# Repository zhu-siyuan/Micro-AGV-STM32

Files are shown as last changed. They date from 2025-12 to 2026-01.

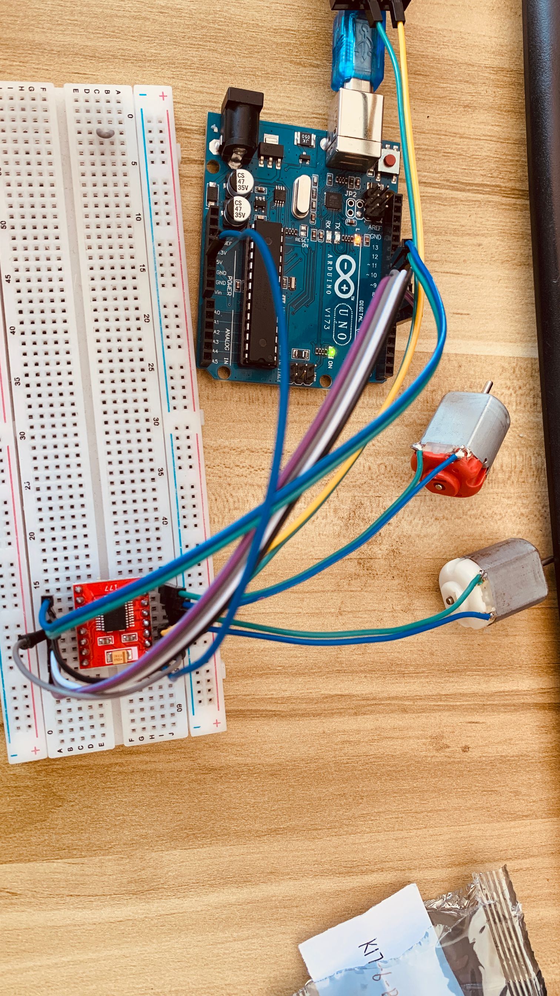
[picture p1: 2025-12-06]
Docs/Datasheets/电机驱动详情/实物接线.png

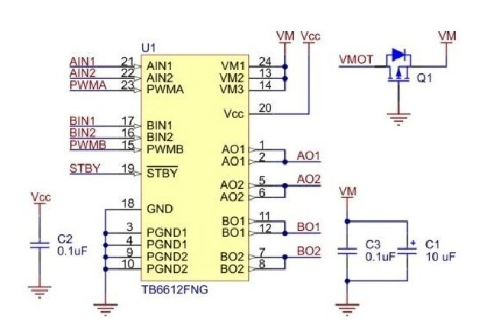
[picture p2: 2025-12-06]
Docs/Datasheets/电机驱动详情/原理图.png

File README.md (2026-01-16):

# 🏎️ Micro-AGV-STM32 (工业级桌面移动机器人)

> **"不仅仅是玩具，而是遵循工业设计标准开发的 Micro-AGV 移动平台。"**

## 📖 项目简介 (Introduction)

本项目旨在研发一款**具备工业级研发标准的桌面级三轮全向移动小车 (Micro-AGV)**。
区别于市面上常见的“飞线+胶带”式玩具车，本项目严格遵循 **SOP (标准作业程序)**，采用 **V模型开发流程**，旨在验证从需求分析、GitHub 版本管理、PCB 集成设计到结构堆叠的全套正规军研发流程。

### 核心特性 (Key Features)
*   **🤖 闭环控制 (PID)**：摒弃开环控制，引入霍尔编码器反馈，实现速度与航向的精准修正。
*   **📡 工业级通信协议**：自定义定长数据帧（帧头+校验+帧尾），具备通信容错与失效保护机制。
*   **🏗️ 模块化软件架构**：基于 HAL 库，严格分层 (Drivers / Middlewares / Application)，解耦硬件细节。
*   **🛡️ 全包裹工业设计**：3D 打印外壳，隐藏式走线与电池仓设计，提升整机一体性。

---

## 🛠️ 系统架构 (System Architecture)

### 1. 硬件选型 (Hardware)
| 模块 | 型号/规格 | 选型理由 |
| :--- | :--- | :--- |
| **主控 MCU** | STM32F103C8T6 | 生态成熟，IO 资源满足 PWM/UART/编码器需求 |
| **电机驱动** | TB6612FNG | 双路 H 桥，高效率，低发热，体积小 |
| **动力系统** | JGA25-370| **带霍尔编码器**，支持 AB 相测速 (PID 基础) |
| **电源系统** | 2×18650 (7.4V) | 配合 LM2596 稳压模块，抗干扰能力强 |
| **通信模块** | HC-05 蓝牙 | 串口透传，兼容性好 |

### 2. 软件架构 (Software)
本项目采用分层架构设计：
- **📂 Application (业务层)**: 状态机管理 (待机/遥控/急停)、指令解析。
- **📂 Middlewares (功能层)**: PID 算法库、运动学解算 (Kinematics)、电机控制逻辑。
- **📂 Drivers (驱动层)**: 基于 STM32 HAL 库封装 GPIO, PWM, UART, EXTI。

---

## 📡 通信协议 (Communication Protocol)

为保证通信可靠性，拒绝单字符控制。采用 **定长数据帧** 格式：
**波特率：** 9600

| 字节索引 | 定义 | 值/说明 |
| :--- | :--- | :--- |
| **0** | **帧头 (Header)** | `0xA5` (固定，用于数据对齐) |
| **1** | **功能字 (Func)** | `0x01`: 遥控模式 <br> `0x02`: PID参数整定 |
| **2** | **数据 X** | X轴速度 (int8, -127~127) |
| **3** | **数据 Y** | Y轴速度 (int8, 预留给全向轮) |
| **4** | **数据 Omega** | 转向速度 (int8, -127~127) |
| **5** | **校验位 (Check)** | Sum Check (前5字节之和的低8位) |
| **6** | **帧尾 (Tail)** | `0x5A` (固定) |

> **失效保护 (Fail-Safe)**: 若连续 500ms 未收到合法数据帧，小车将自动急停。

---

## 📂 目录结构 (Directory Structure)
```text
Micro-AGV-STM32/
├── Docs/               # 项目文档 (可行性报告, Datasheets)
├── Hardware/           # 硬件工程 (Altium Designer/嘉立创 EDA)
│   ├── Schematic/      # 原理图
│   └── PCB/            # PCB源文件 & Gerber
├── Mechanical/         # 结构工程 (SolidWorks)
│   └── Export/         # STL/DXF 加工文件
├── Firmware/           # 嵌入式代码 (Keil/VSCode)
│   ├── Core/           # CubeMX 生成代码
│   ├── Drivers/        # 硬件驱动
│   └── App/            # 核心业务逻辑
└── README.md           # 项目说明书
```
---

## 👥 核心团队 (Team)

| 成员 | 角色 | 职责 |
| :--- | :--- | :--- |
| **@zhu-siyuan** | **PM & Software** | 项目管理、架构设计、STM32 固件开发、PID 调试 |
| **@min-huang-HW** | **Hardware** | 硬件选型、原理图/PCB 设计、电路焊接与测试 |
| **@yuying-qin-MD** | **Mechanical** | 工业设计、3D 建模 (SolidWorks)、结构总装 |

---

> Powered by **Micro-AGV Research Team**. 
> *Documentation is code.*

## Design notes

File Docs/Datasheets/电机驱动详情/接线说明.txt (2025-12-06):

uno的控制引脚接线可以看一下代码程序

*这个模块驱动电机需要STBY和VM同时给3.3V或者5V的高电平

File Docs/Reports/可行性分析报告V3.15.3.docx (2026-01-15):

桌面级三轮全向移动小车

可行性分析报告

编写： | 朱思源，覃钰莹，黄敏
审核：
版本号： | 3.15.3
修改时间： | 2026年1月5日

目 录

# 1、 引言

## (1) 编写目的

为编写产品开发可行性分析报告，旨在系统性评估项目的技术实现路径、资源匹配度及风险边界。该报告通过跨部门协同论证，确保核心设计方案在成本、周期与性能三者间取得最优平衡，为决策层提供量化依据，避免因关键要素预判缺失导致的重大方向偏离或资源浪费。

### 1. 项目背景

目前市面上常见的入门级蓝牙小车（如淘宝通用套件）普遍存在以下痛点：

(1) 工程化程度低：硬件集成粗糙，常采用裸露的“飞线”连接方式，线束杂乱且缺乏基本的捆扎与应力释放设计。这导致在运动或振动中连接器易松动、线材易疲劳断裂，供电与信号稳定性差，整体结构脆弱，故障率高。
(2) 软件架构缺失：配套代码多为单一文件的顺序“面条式”堆砌，硬件驱动、控制逻辑与用户交互高度耦合。缺乏清晰的分层（如驱动层、算法层、应用层）与模块化设计，导致代码可读性差、功能复用困难，任何修改都可能引发意外问题，严重阻碍二次开发与教学深化。
(3) 用户体验粗糙：往往仅提供最基础的遥控功能，缺乏运行状态提示（如电量、实时速度、连接状态）等直观反馈。外观多为开放式裸板或简易亚克力叠层，缺乏一体化封装与人性化设计，使得产品显得廉价、不稳固，且操作互动感薄弱。
(4) 基于公司对新人的培养要求，本项目组计划以“三轮差速底盘”为核心载体，不追求车体体积的盲目扩大，而是追求单位体积内的技术密度与工艺完成度。我们将挑战在有限的尺寸内，实现稳定的直线循迹、丝滑的蓝牙操控以及极具科技感的外观封装。

### 2. 术语定义

为了确保项目组内部沟通的一致性，特定义以下核心术语：

(1) Micro-AGV：微型自动导引车[1]。本项目中指代我们研发的蓝牙小车，强调其不仅是玩具，而是遵循工业设计标准开发的移动平台。
(2) 三轮差速模型(Differential Drive)：通过控制左右两个驱动轮的速度差来实现转向，配合后置/前置万向轮支撑的运动结构。
(3) SOP(Standard Operating Procedure)：标准作业程序。本项目中特指包括Git代码提交规范、PCB设计规范、结构公差分析在内的一系列研发铁律。
(4) MVP(Minimum Viable Product)：最小可行性产品。指优先交付核心功能（如蓝牙遥控跑通），再迭代高级功能（如外观件、PID调优）的开发策略。
(5) 开环控制（Open-Loop Control）：开环控制是指控制系统不依赖输出结果的反馈信息，仅根据预设的输入指令或控制规律直接驱动执行机构，对被控对象进行控制。
(6) 闭环控制（Closed-Loop Control）：闭环控制（又称反馈控制）是指控制系统通过传感器检测被控对象的实际输出，并将其与目标值（设定值）比较，根据偏差调整控制指令，直至输出接近或达到目标值。
(7) PWM(Pulse Width Modulation)：脉冲宽度调制。本项目中用于通过调节占空比来精确控制电机的转速，是调速的核心手段。
(8) UART透传(Serial Transparent Transmission)：蓝牙通信模式。指手机端与车载蓝牙模块之间建立一条“隐形的串口线”，数据不经处理直接转发给MCU，确保通信协议的自定义灵活性。
(9) 固件(Firmware)：运行在STM32微控制器内部的底层驱动程序与控制逻辑，区别于运行在手机端的APP软件。
(10) PID（Proportional-Integral-Derivative）：PID控制器是一种在工业控制、机器人、自动化系统中广泛使用的反馈控制算法，通过“比例（P）”、“积分（I）”、“微分（D）”三个环节的组合，根据系统输出与目标值的偏差自动调整控制量，使系统输出快速、稳定地逼近目标值。
(11) 阶跃响应（Step Response）：系统在输入为阶跃信号时所产生的输出随时间变化的过程。

# 2、 现有产品分析

## (1) 企业现有产品分析

企业现有一款四轮蓝牙小车，如图1原有小车，其是基于STM32和标准直流电机的低精度运动平台。该小车动力强劲，外观炫酷，可以实时响应手机蓝牙信号，也可出色的完成转向等基本任务。

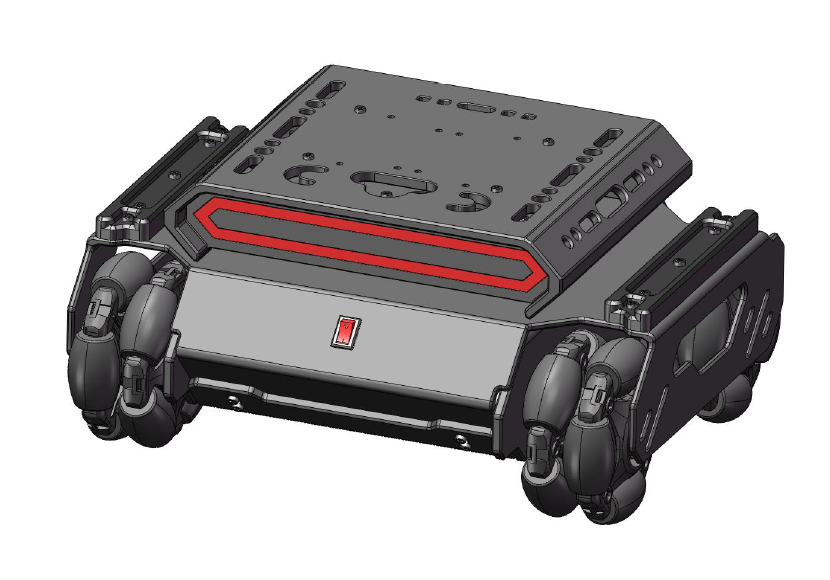
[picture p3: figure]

图1原有小车

不过，该小车有严重的局限性。该小车动力单元不带编码器，无法实时反馈运动情况；体型较大，在转向时不够灵活；结构封闭，无法扩展固件，维护难度和成本增加。

## (2) 外部产品分析

目前市场上针对大学生的三轮智能小车套件，普遍存在“重功能堆砌，轻工程质量”的问题。

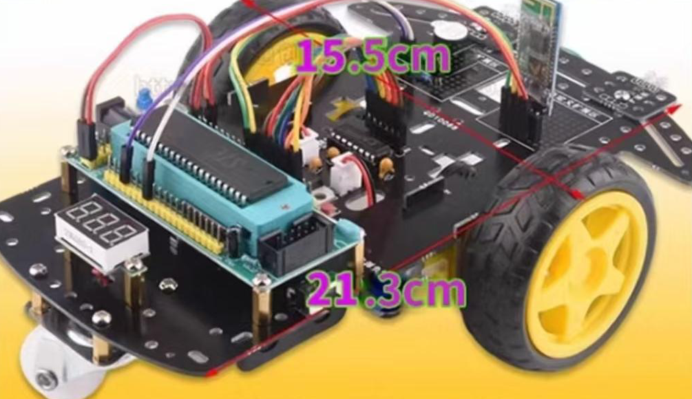
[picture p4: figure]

图2[^1]淘宝蓝牙小车

### 1. 主要痛点：

#### (1) 物理结构脆弱，可靠性不足

机械结构简陋：普遍采用开放式“三明治”亚克力板结构，核心电子部件与线束完全暴露。亚克力材质脆性高、易开裂，缺乏基本的防护外壳，使得系统在碰撞、振动或灰尘环境中极为脆弱，故障风险高。电气连接与防护缺失：内部大量使用杜邦线进行“飞线”连接，在运动振动下极易松动脱落，导致断电或信号中断。系统未设计静电放电（ESD）防护与电磁屏蔽，抗干扰能力差，且线束杂乱，大幅增加了调试与维护的难度。

#### (2) 控制算法开环，运动性能低下

策略层面落后：目前普遍采用开环PWM控制，仅向电机发送指令而不检测实际转速与姿态。由于电机性能差异、轮胎磨损及地面摩擦不均等固有物理偏差，导致车辆无法维持直线行驶，产生持续偏航。缺乏感知与反馈：控制系统未集成编码器、IMU等传感器，形成“盲控”。算法无法感知实际运动状态与预期的偏差，因此不具备动态补偿能力。这使得系统行为不可预测、不精确，完全依赖于操作员的手动修正，无法实现任何形式的自主精确运动。

#### (3) 工程规范缺失，难以协作与迭代

软件架构混乱：代码通常集中在一个数千行的main.c文件中，硬件驱动、业务逻辑和应用程序高度耦合。这种架构导致代码可读性、可维护性极差，任何硬件改动或功能升级都需要全局修改与测试，风险与成本高昂。开发管理原始：项目未使用任何版本控制系统（如Git），代码迭代历史与分支管理完全缺失，协同开发困难。技术文档仅有简单接线图，缺乏设计文档、接口说明与测试记录，导致知识无法传承，严重阻碍了项目的二次开发、团队协作与长期可持续发展。

# 3、 新产品说明

## (1) 新产品开发意义

本项目旨在设计并研发一款具备工业级研发标准的桌面级三轮全向移动小车（Micro-AGV）。本报告的编写目的在于：

### 1. 验证标准化研发流程（SOP）：

借此项目跑通从需求分析、GitHub版本管理、PCB集成设计到结构堆叠的全套正规军研发流程，摒弃“飞线+胶带”的作坊式开发。

### 3. 建立技术基线：

针对三轮底盘[2]的运动学特性，验证PID闭环控制算法与蓝牙通信协议的可靠性，为后续更复杂的自动化项目积累底层驱动库。

### 4. 产品化尝试：

在通用裸机底盘的基础上，通过工业设计赋予其完整的外观防护与交互逻辑，探索从“功能原型”向“交付级产品”跨越的可行性。

## (2) 需求分析

表1需求分析表

维度 | 现有产品不足 | 新产品改进方案
运动精度 | 电机无码器，精度差 | 电机带编码器+PID实时修正
灵活度 | 小车体积大 转向不灵活 | 总重＜600g
可拓展性 | 无可拓展性 | 外壳和PCB预留其他固件空位

表2小车电机需求指标

需求指标 | 数值/要求 | 来源说明
转矩 | 0.006 N·m | 550g车重、64mm轮径 摩擦系数0.02、加速度0.5m/s²
转速 | 100r/min | 匹配电机额定转速，对应车速0.335m/s
峰值转矩 | ≈0.012 N·m | 单轮失效极端工况：一轮悬空/打滑 另一轮承担全部负载与加速需求。
控制精度 | 两轮速度同步误差<0.34% | 2米偏移≤15 cm 对应的航向偏差与速度差要求
编码器 | 双向霍尔编码器 | 用于速度闭环控制。
控制方式 | 双轮独立速度闭环 | 编码器反馈+PID控制。
校准 | 轮径差异软件补偿 | 消除主要机械不对称性。

## (3) 影响

### 1. 产品体系结构

核心需求是对底层硬件架构进行升级。需重新设计包含编码器的驱动电机，以提供精准的转速反馈；同时，需为陀螺仪（IMU）预留出物理安装位与电路接口，为高精度姿态感知与控制奠定硬件基础。

### 5. 软件系统

输入层：整合通信接口与硬件抽象，统一处理遥控指令及传感器原始数据。

任务层：作为核心，以独立线程运行PID控制、运动补偿等算法，实现精准闭环控制。

输出层：负责电机驱动与系统状态机管理，确保控制指令稳定、安全地执行。

### 6. 系统运维

优势：模块化设计支持后续增加陀螺仪和超声波传感器。

挑战：算法和代码标准要求极高。

### 7. 开发组织

组建跨学科团队：嵌入式硬件工程师、嵌入式软件工程师、结构工程师。

### 8. 经费开支

增量成本：市场行情稳定，无明显增量。

投资回报：不对外出售，不考虑回本。

## (4) 局限性

外当前方案仍存在一定局限：外观较为初级；转向精度最终受限于执行机构与算法调优；系统的可拓展性虽有设计，但具体实现需后续验证与完善。

# 4、 技术分析和时间分析

## (1) 技术条件方面的可行性

### 1. 结构可行性

车身材质：3D打印主体+金属连接件；

车身尺寸：长度190mm×宽度138mm×高度95mm。

#### (1) 需求分析

项目 | 电机能力（单电机） | 小车需求（单电机） | 对比结果
额定转矩 | 0.0785N·m | 0.006N·m | 合格
峰值转矩 | 0.4315N·m | 0.012N·m | 合格
额定转速 | 100±10%r/min | 100r/min | 合格
空载转速 | 130r/min | 无需高速 | 合格
编码器 | 有（霍尔双向） | 必需（闭环控制） | 合格
功率（输入） | 3W（6V×0.5A） | 机械功率约0.063W | 合格
最大车速 | 0.435m/s（空载） | 0.34m/s（预期） | 合格
控制方式 | PWM调速 | 需速度闭环 | 合格

表3 JGA25-370电机性能匹配度

表4电机与目标可行性对照表

目标 | 需要条件 | 当前设备满足情况 | 可行性
及格线 （2米≤20cm偏） | 1.动力足够 2.两轮速度基本一致 3.地面平坦 | 1.动力充足 2.可预先校准占空比 3.一般实验室地面满足 | 高
挑战线 （2米≤15cm偏） | 1.动力足够且响应快 2.双轮速度闭环 3.航向实时反馈与纠偏 4.地面不打滑 | 1.动力充足 2.有编码器可速度闭环 3.仅编码器难以稳定航向 4.依赖地面摩擦均匀 | 加陀螺仪后可达

#### (4) 整车结构

图3蓝牙小车采用工业风箱体式整体造型，线条简洁，几何轮廓规整。上壳顶部嵌入一块透明视窗，视窗表面增设两条平行横向装饰条，能通过透明区域直观看到内部元件布局；视窗与装饰条一体化为上壳部分，底盘和外围一体化为车厢主体。上壳与车厢主体用螺栓连接，建模无多余拼接缝隙。行走系统采用双主动轮+单万向轮的经典布局，主动轮对称分布于车身两侧，万向轮置于尾部，轮组与车身底板的连接位设计紧凑[3]，与箱体造型形成协调的比例关系。

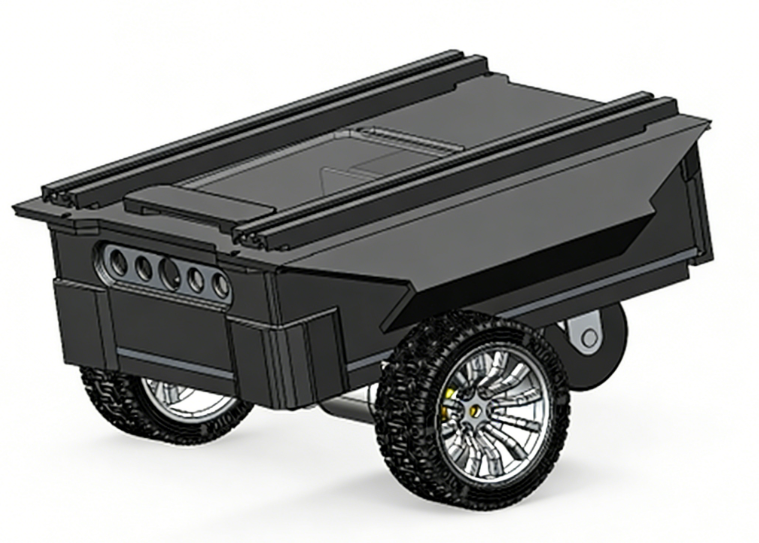
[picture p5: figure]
一辆银色的车 AI 生成的内容可能不正确。

图3小车SolidWorks模型图

#### (5) 底盘部分

图4的底盘部分由一块自开孔底板和2个JGB25-370直流减速电机构成，由电机输出轴+联轴器+螺丝锁紧进行连接，电机的固定双支座悬梁式[4]安装方案，能有效约束电机在各方向的位移与振动，保证其在高负载工况下的定位精度与运行平稳性。

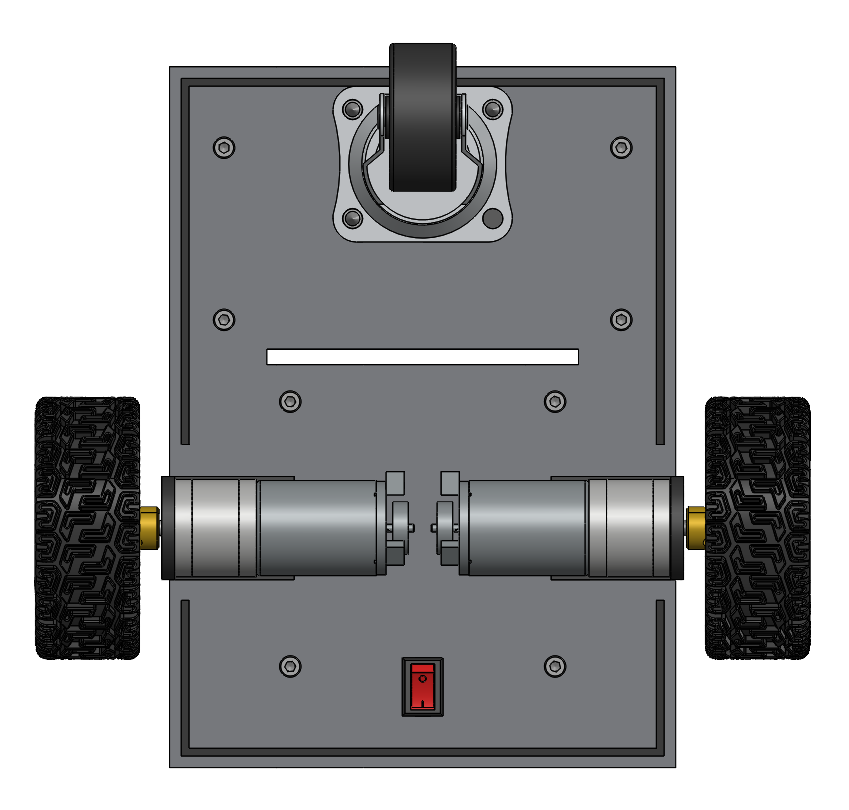
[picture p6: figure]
图示, 工程绘图 AI 生成的内容可能不正确。

图4底盘部分

#### (6) 底盘布局

图5展示分区的布局策略：电池组作为重质量单元，布置于底盘低重心区域（后部）以提升稳定性；主控PCB、传感器等电子单元集中于防护性好的中部舱体内；线束通过预设通道走线，确保整洁与安全。

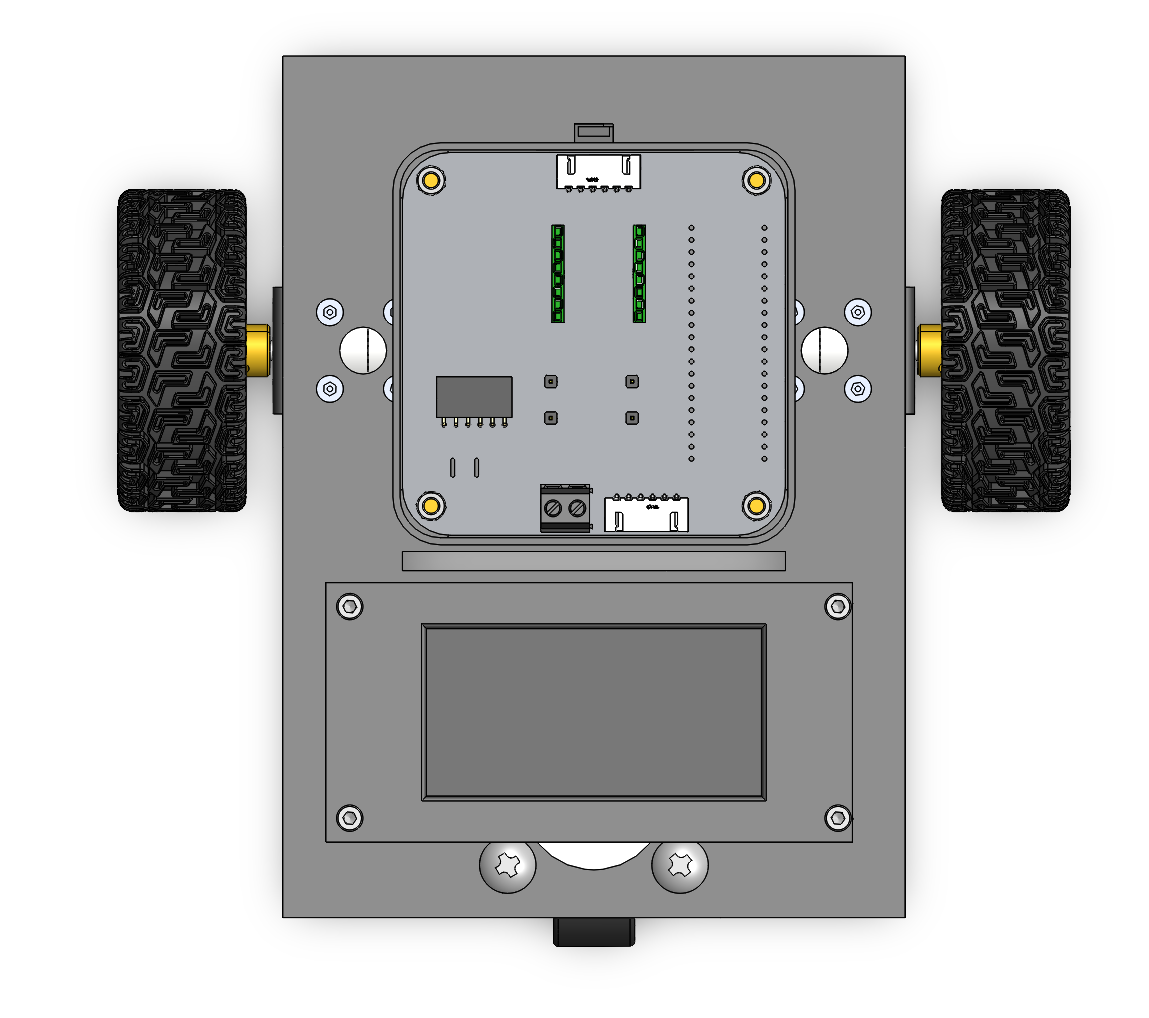
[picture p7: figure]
图片包含 游戏机, 钟表 AI 生成的内容可能不正确。

图5底盘布局

#### (7) 电池盒布局

采用M3标准六角铜柱作为PCB与安装底板的机械连接件，安装底板上预设的螺纹孔阵列与PCB板上的安装过孔位置完全一致，该方式在PCB板与安装平面之间形成了稳固的机械连接和必要的散热间隙。电池包外形与底盘预留的电池舱空间完全匹配，四周留有必要安装余量。

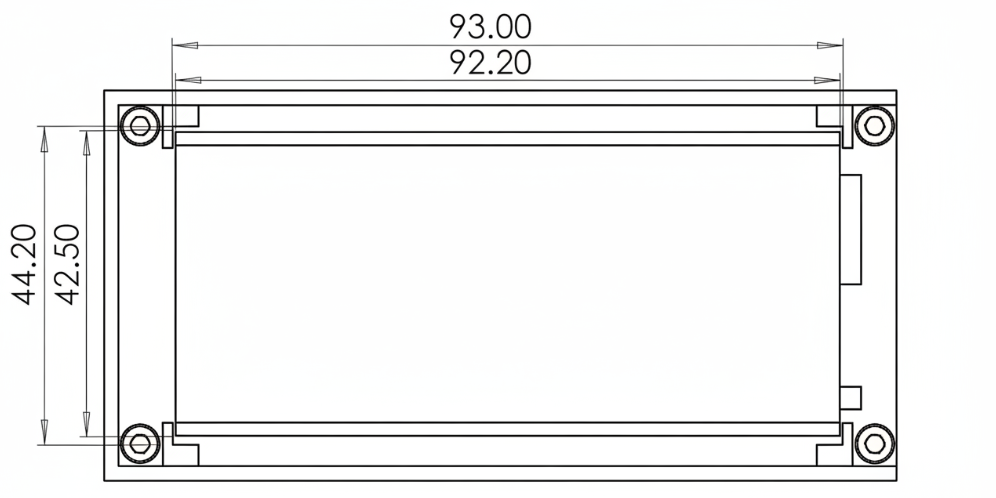
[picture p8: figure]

图6电池盒布局

### 9. 硬件可行性

#### (1) 电池

18650锂电池×2（串联）：18650电池直径18mm，尖头电池长67mm，平头电池长65mm，单节电池标称电压：3.7V，满电电压：4.2V。优势：容量大、放电稳定、可充电循环使用。

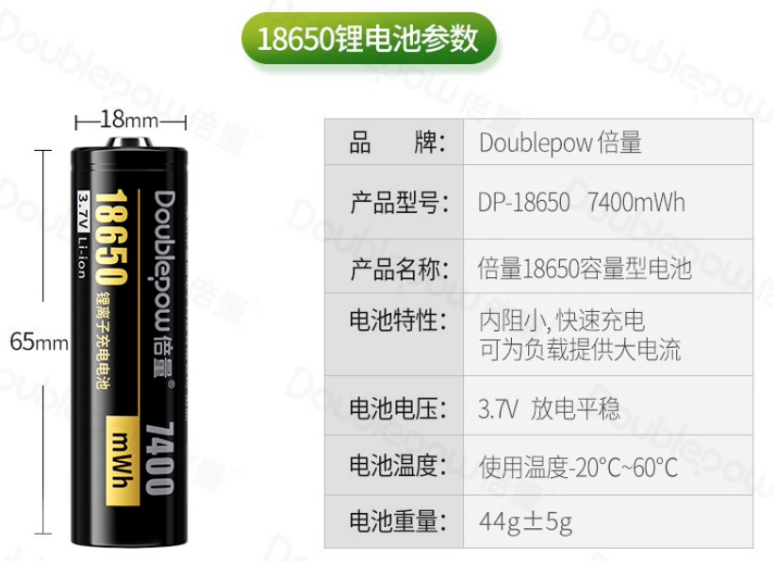
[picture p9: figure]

图7电池详情

#### (8) DC-DC自动升降压稳压电源模块s08

输入电压为3-15V，稳定输出5V；输出电流为200mA；虽有开关纹波，但对STM32数字电路影响微乎其微；发热小；核心优势在于其“宽电压自适应、高效一体集成”的特性——它能自动识别并稳定适配波动较大的输入电压（如锂电池的7.4V-6.4V变化范围），无需手动切换即可同时满足系统中不同电压等级设备的供电需求（如5V主控和3.3V外设），且采用开关电源设计，转换效率高达90%以上，发热极低，体积紧凑，大幅简化了多电源系统的设计复杂度，确保了整个小车系统在电池电量变化时仍能稳定可靠运行，是集成化移动平台的理想电源解决方案。

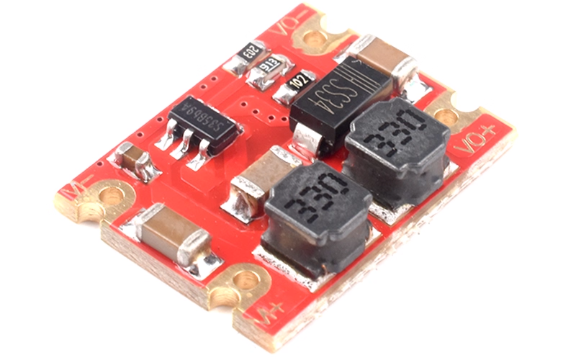
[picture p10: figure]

图8HC-05外观图

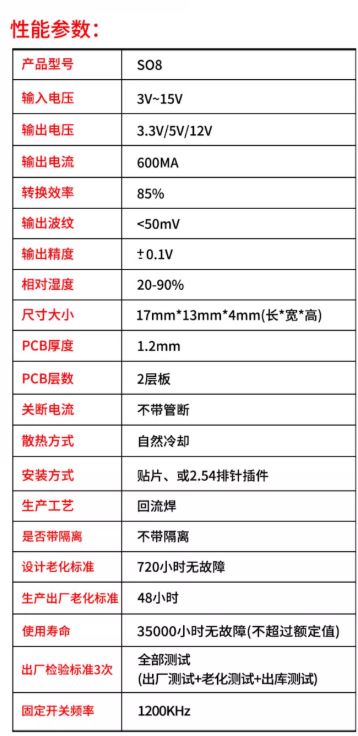
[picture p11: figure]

图9S08详细参数

#### (9) STM32C8T6主控[5]

对电机闭环的“硬件级”支持

编码器读取：其高级控制定时器（如TIM1,TIM2,TIM3,TIM4）自带正交编码器接口模式，能直接读取A、B相脉冲，硬件自动计数方向，CPU无需干预。

PWM生成：同一定时器可同时生成多路带死区互补的PWM，完美驱动电机驱动桥，控制精度和响应速度远超软件模拟[6]。

充沛的扩展空间：20KB的RAM允许你运行更复杂的算法（如滤波、路径规划），富余的Flash可以添加更多功能（如OLED菜单、蜂鸣器音效、多种控制模式）。

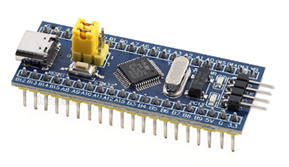
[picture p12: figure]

图10STM32F103C8T6外观图

#### (10) TB6612FNG电机驱动

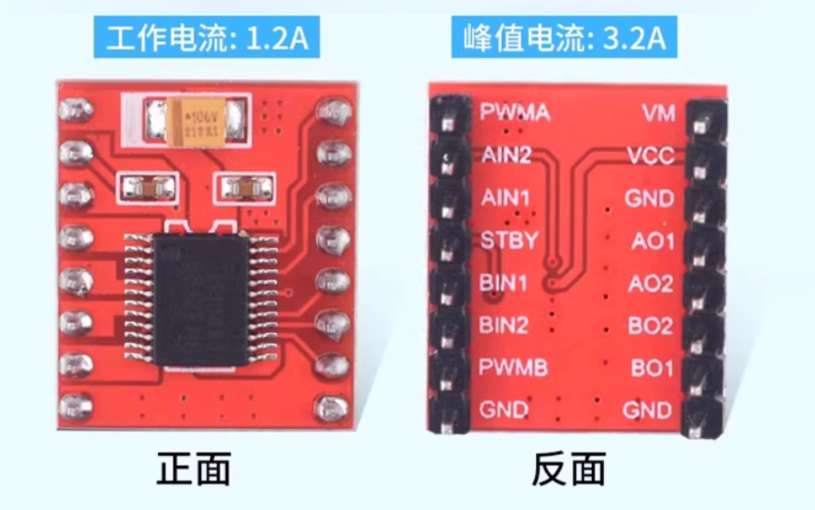
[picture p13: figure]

图11TB6612FNG电机驱动外观

优势：双路H桥，一个模块可以控制两个电机、支持正反转/PWM调速、支持高达100kHz的PWM频率，高频PWM使电机电流更平滑，消除人耳可闻的啸叫声，小车运行更安静平顺；TB6612FNG内置多重保护（过热关断、欠压锁定、有限流功能、CMOS锁定保护），大幅降低烧毁风险；低功耗、抗干扰强；体积小（13*17mm）。

#### (11) HC-05

核心优势在于其“主从一体”的卓越灵活性与强大的可配置性——它不仅可作为从机被手机连接实现基础遥控，更能切换为主机主动搜索并连接其他蓝牙设备（如另一台小车或信标），为项目预留了自动跟随、多车协作等高级功能的硬件基础；其完善的AT指令集支持深度定制与实时状态查询，独立STATE引脚可精确反馈连接状态以增强系统安全性，且作为经典蓝牙模块，其连接稳定、延迟低，配合3.3V电平版本能与STM32完美兼容，是兼顾当前可靠遥控与未来智能扩展的理想选择[7]。

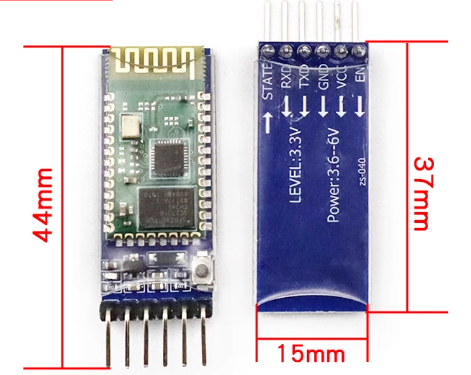
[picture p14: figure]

图12HC-05外观图

#### (12) 原理图&PCB

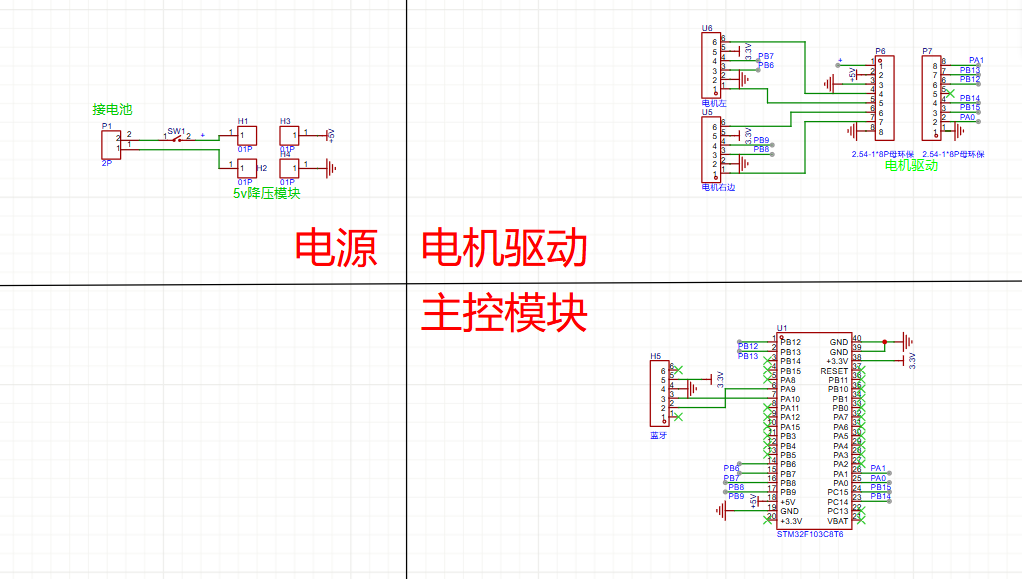
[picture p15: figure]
电脑屏幕的照片上有文字 AI 生成的内容可能不正确。

图13小车原理图

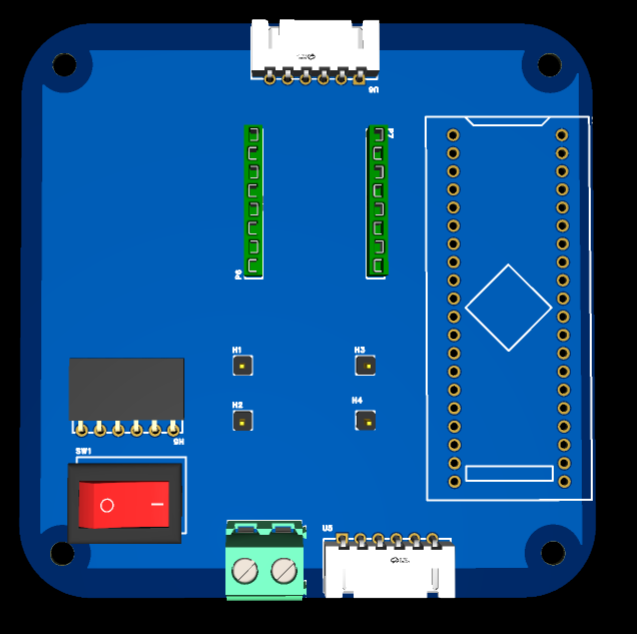
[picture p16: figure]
7ff3fd760cd646444fed9fada3194899

图14小车PCB图

### 10. 软件可行性分析

#### (1) 软件架构设计

本项目摒弃传统的“前后台轮询”模式，采用分层解耦架构，将软件划分为三个独立层级。

硬件抽象层：利用STM32CubeMX生成代码，封装GPIO、PWM、UART等底层资源。作用：向下屏蔽硬件差异。若将来更换主控芯片（如换成ESP32），只需重写此层，上层逻辑无需变动。

功能模块层：独立封装PID算法库。交互方式：该层不直接操作硬件，仅通过输入（目标速度、当前编码器数值）计算输出（PWM占空比），实现纯数学逻辑的复用。

业务逻辑层：实现状态机管理（待机/遥控/故障保护）。数据流向：蓝牙中断接收—>协议解析—>目标值更新—>PID计算—>电机驱动执行。

#### (2) 架构选型辩证与权衡

针对上述架构，我们进行了如下可行性与利弊分析：

必要性：解耦需求：传统“面条式代码”将串口接收与电机控制混写在main.c中，导致“牵一发而动全身”。分层架构确保了通信模块与驱动模块的独立性；团队协作：硬件组调试底层驱动时，不会干扰软件组开发上层算法，便于并行开发。

缺点：代码量增加：相比直接操作寄存器，分层架构引入了更多的函数调用和结构体定义，增加了Flash占用；执行效率折损：函数封装会带来微秒级的压栈/出栈开销。

缺点的可忽略性：性能冗余：STM32F103主频72MHz，对于10ms一次的PID控制周期，其算力绰绰有余，上述开销可忽略不计；工程价值优先：在本SOP验证项目中，代码的可维护性与可读性远比1%的极限性能优化更重要。

#### (3) 通信协议可行性

为解决蓝牙无线传输可能存在的丢包与粘包问题，采用“有限状态机(FSM)+定长数据帧”的解析方案：

协议定义：帧头(0xA5)+功能字+数据段+校验和+帧尾(0x5A)[8]。

可靠性分析：校验机制：引入Sum Check，防止因电磁干扰导致的数据篡改（如将“停止”指令误读为“全速”）。

失效保护：软件设定“看门狗”逻辑，若超过500ms未收到合法数据帧，小车自动急停。

#### (4) 开发工具链

代码生成：STM32CubeMX(配置引脚与时钟)

IDE/编译器：Keil MDK 5+VSCode

版本管理：GitHub

#### (5) 接口控制

交互接口：明确主控板供电电压、电机驱动接口引脚定义。

机械接口：明确PCB板定位孔尺寸（例如：M3螺丝，孔距30mm*40mm），电池仓的具体尺寸限制（长宽高）。

数据接口：确定蓝牙模块的波特率9600。

## (5) 时间分析

按照正常的运作方式，开发时间充裕，但目前还没有投入市场的打算。

# 5、 成本与收益分析

## (1) 成本分析

表5结构BOM

序号 | 名称 | 规格 | 单价（元） | 数量（个/套） | 运费（元） | 总价（元）
1 | 大简3D打印耗材 | PETG银色1kg | 25.59 | 2 | 0 | 51.18
2 | R3D3D打印耗材 | PETG透明色1kg | 23.9 | 1 | 0 | 23.9
3 | M3螺栓组 | M3x9mm（100粒） | 5.5 | 1 | 0 | 5.5
4 | M3螺栓组 | M3x10mm（100粒） | 5.3 | 1 | 0 | 5.3
5 | M3螺栓组 | M3x14mm（100粒） | 7.5 | 1 | 0 | 7.5
6 | M3双通铜柱 | M3x6mm（30粒） | 3.6 | 1 | 0 | 3.6
7 | M3双通铜柱 | M3x21mm（15粒） | 4.5 | 1 | 0 | 4.5
8 | M3六角铜柱 | M3×6+10mm（20粒） | 4 | 1 | 1 | 5
9 | 黑色十字扁头螺丝钉 | M3×8mm（50个） | 3.64 | 1 | 0 | 3.64
10 | M3绝缘橡胶垫 | 3×6×1mm（200个） | 2.02 | 1 | 0 | 2.02
11 | 直流电机套装 | JGA25-370电机配d65mm轮胎 | 27.8 | 2 | 6 | 61.6
12 | 万向轮 | 1.5英寸 | 3.08 | 1 | 0 | 3.08
| 总价 | | | | | 176.82

表6硬件BOM

序号 | 名称 | 单价（元） | 数量（个/套） | 运费（元） | 总价（元）
1 | TB6612FNG电机驱动板模块 (https://item.taobao.com/item.htm?id=607254624071&from=cart&skuId=5205675671358&upStreamPrice=140) | 4.8 | 3 | 0 | 14.4
2 | 18650锂电池*2加充电盒 | 27 | 1 | 0 | 27
3 | 电池盒 | 1.7 | 3 | 0 | 5.1
4 | DC-DC自动升降压稳压电源模块s08 | 5.4 | 5 | 0 | 27
5 | STM32F103C8T6 | 7.59 | 3 | 0 | 22.77
6 | HC-05 | 14.46 | 3 | 0 | 43.38
7 | xh2.54 6p | 0.0778 | 50 | 0 | 3.89
8 | 弯针排母 | 0.3 | 10 | 0 | 3
9 | 洞洞板 | 1.225 | 2 | 0 | 2.45
10 | 面包板 | 5.92 | 1 | 0 | 5.92
11 | 杜邦线 | 8.57 | 1 | 0 | 8.57
12 | 18650锂电池 | 7 | 3 | 0 | 21
| 总价 | | | | 184.48

总预算：440元

附件：BOM1.6.xlsx (https://www.kdocs.cn/l/ceW9FXP8i8jJ)

## (2) 收益分析

本项目无投入市场想法，故无收益。

# 6、 产品开发计划

## (1) 人力资源分析

为了确保协作效率，各成员职责划分如下：

### 1. 朱思源

(1) 负责项目整体进度把控与GitHub仓库维护。
(2) 负责STM32底层驱动编写、通信协议解析及PID算法调试。

### 2. 黄敏

(1) 负责元器件选型与采购(BOM)。
(2) 负责电源管理系统与电机驱动电路的焊接/连接与电气安全性测试。

### 3. 覃钰莹

(1) 负责整车外形设计(SolidWorks/CAD)。
(2) 负责结构件的3D打印及整车总装。

## (2) 开发环境分析

表7开发环境分析

类型 | 名称 | 时间节点 | 价格
EDA软件 | Altium Designer | 电路原理图与PCB设计 （核心板与拓展板） | 免费
3D建模软件 | SolidWorks | 机械结构设计建模 装配体检查 | 免费
IDE/编译器 | STM32CubeIDE | 集STM32CubeMX、代码编写、编译、调试于一体的官方免费开发环境 | 免费
调试工具 | ST-Link V2仿真器 | 程序烧录与调试 （SWD接口） | ~50
| 数字万用表 | 测量电压、电流、通断等基础电气参数 | ~150
| 数字示波器 | 观测关键信号波形 （如PWM、通信时序） | ~1500
测量工具 | 热电偶/温枪 | 测量芯片及外壳内部温度，验证散热设计 | ~200
焊接工具 | 恒温焊台 | 焊接与返修贴片元件 | ~300
版本控制 | Git(GitLab/Gitea)硬件源码、软件代码、设计文档的版本管理与团队协作 | Git(GitLab/Gitea)硬件源码、软件代码、设计文档的版本管理与团队协作 | 免费

## (3) 开发流程分析

表7开发环境分析续表

本项目采用分阶段并行开发的流程，以提升效率并确保关键节点可控。

### 1. 准备阶段

本阶段旨在完成所有前期设计与规划工作，为后续开发奠定清晰基础。

(1) 撰写可行性分析与需求冻结：完成初步技术论证，并正式确定产品核心功能与性能指标，形成冻结的需求文档作为后续开发基准。
(2) 搭建GitHub协作环境：创建项目代码仓库，建立分支管理策略（如Git Flow）与文档结构，统一团队协作规范。
(3) 准备元器件选型与采购：完成关键元器件的选型评估，形成物料清单，并启动采购流程，确保硬件开发物资就位。

### 2. 模块开发阶段

(1) 硬件组：原理图绘制（或接线图定义）、焊接与电气测试。
(2) 结构组：3D建模、切片与打印。
(3) 软件组：底层驱动(HAL)编写与通信协议实现。

### 3. 系统集成阶段

(1) 机电联调：将电路板装入车身，验证结构稳定。
(2) 整车调试：注入控制算法，调试PID参数。

## (4) 进度里程碑

表8进度里程碑

序号 | 分工 | 任务名称 | 天数 | 开始日期 | 结束日期 | 二 | 三 | 四 | 五 | 六 | 日 | 一 | 二 | 三 | 四 | 五 | 六 | 日 | 一 | 二 | 三 | 四 | 五 | 六
| | | | | | 30 | 31 | 1 | 2 | 3 | 4 | 5 | 6 | 7 | 8 | 9 | 10 | 11 | 12 | 13 | 14 | 15 | 16 | 17
1 | | 元旦放假 | 3 | 2026/01/01 | 2026/01/03
2 | | 修改文档 | 7 | 2025/12/30 | 2026/01/05
3 | | 三个部门开始采购到确认收货 | 7 | 2026/01/06 | 2026/01/12
4 | 结构 | 建模 | 7 | 2025/12/30 | 2026/01/05
5 | | 结构打印 | 7 | 2026/01/06 | 2026/01/12
6 | | 结构组装 | 3 | 2026/01/10 | 2026/01/12
7 | | 结构测试 | 3 | 2026/01/10 | 2026/01/12
8 | 硬件 | 画PCB | 7 | 2025/12/30 | 2026/01/05
9 | | 测试PCB板 | 3 | 2026/01/06 | 2026/01/08
10 | | PCB纠错并改正 | 2 | 2026/01/08 | 2026/01/09
11 表8进度里程碑续表 | | 重新画板并下单 | 4 | 2026/01/09 | 2026/01/12
12 | | 杜邦线面包板同步进行备用方案 | 7 | 2026/01/06 | 2026/01/12
13 | 软件 | GitHub仓库搭建 | 2 | 2025/12/30 | 2025/12/31
14 | | 软件框架搭建 | 7 | 2025/12/30 | 2026/01/05
15 | | 学习电机控制 | 2 | 2026/01/06 | 2026/01/07
16 | | 锻件驱动配置 | 2 | 2026/01/08 | 2026/01/09
17 | | 编写协议栈代码 | 2 | 2026/01/10 | 2026/01/11
18 | | 借用公司编码电机编写PID | 2 | 2026/01/12 | 2026/01/13
19 | | 软件调试参数 | 3 | 2026/01/14 | 2026/01/16
20 | | 验收 | 1 | 2026/01/17 | 2026/01/17

# 7、 技术风险及应对

## (1) 技术风险

### 1. 电源系统干扰风险

风险描述：直流电机在启动、堵转或急停瞬间，会产生极大的瞬时电流（涌流）。若电源回路设计余量不足或去耦不良，将引发供电网络电压的瞬间跌落，可能导致微控制器（MCU）因电压过低而意外复位或程序跑飞，致使系统失控。

应对措施：硬件层面：在电机驱动模块的电源输入端、以及MCU的电源入口处，并联大容量（如100-1000μF）的电解电容进行储能与缓冲，以抑制电压突变。软件层面：在单片机初始化代码中，开启并配置其内部的欠压复位功能。该功能能在电压低于安全阈值时，强制系统进入有序的复位流程，而非不可预测的异常状态，从而增强系统的鲁棒性。

### 11. PCB初版失效风险

风险描述：首次设计、打样并焊接的PCB，可能存在未预见的设计错误（如原理图错误、封装不符、布线缺陷），或焊接过程中出现故障，导致整板无法正常工作，从而阻塞硬件调试进程。

应对措施：提前准备备选实施方案。在等待或调试PCB期间，可立即转入面包板原型验证阶段。使用面包板、杜邦线等基础工具，快速搭建核心电路（MCU最小系统、电机驱动连接等），确保关键逻辑和驱动软件能够先行开发与测试，不因PCB问题导致项目全面停滞。

## (2) 市场风险

物流延期：临近圣诞元旦，快递可能滞后。

应对：物料未到期间优先进行软件仿真与结构建模，并行推进。

## (3) 项目管理与组织实施风险

应对：提前在一周内（T+7节点）完成核心功能联调，考试周进入“低功耗维护模式”，仅做文档整理，不进行高强度开发。

# 8、 效益评价与分析

## (1) 经济效益分析：

### 1. 项目背景：

目前市面上常见的入门级蓝牙小车（如淘宝通用套件）普遍存在以下痛点：

(1) 工程化程度低：线束裸露杂乱，缺乏应力释放设计，连接不可靠。
(2) 软件架构缺失：代码多为“面条式”堆砌，缺乏分层与模块化，难以维护和扩展。
(3) 用户体验粗糙：缺乏直观的交互反馈与外观封装。
(4) 基于公司对新人的培养要求，本项目组计划以“三轮差速底盘”为核心载体，不追求车体体积的盲目扩大，而是追求单位体积内的技术密度与工艺完成度。我们将挑战在有限的尺寸内，实现稳定的直线循迹、丝滑的蓝牙操控以及极具科技感的外观封装。

### 12. 数据收集：

预计成本约440元（已考虑装置调试过程中电路板、电机的损毁）。

### 13. 计算收益：

目前没有对外出售的能力与想法，故无经济收益。

### 14. 分析结果：

该项目暂时无法带来经济效益。

## (2) 社会效益评价：

### 1. 结论：

社会效益显著。

### 2. 分析：

团队凝聚力：项目实施过程中，团队成员相互协作，凝聚力显著提升。

个人能力提升：团队成员通过项目实践，掌握了更多专业知识和技能，个人能力得到提升。

# 9、 结论

本项目在技术、经济、市场和时间等方面均具备较高的可行性。通过技术创新和成本优化，项目具有显著的性价比优势。建议批准项目启动，并在实施过程中严格控制成本、优化技术方案，确保项目成功实施并实现预期效益。

# 参考文献

[1] 解铁陶。基于STM32单片机的巡检机器人自动避障控制方法[J].工业控制计算机，2025,38(11):160-162+167. (https://kns.cnki.net/kcms2/article/abstract?uniplatform=NZKPT&language=CHS)
[2] 潘良,佘小明,傅川,等.小型通用轮式电动底盘设计与试验[J].农机化研究,2023,45(09):240-244. (https://kns.cnki.net/kcms2/article/abstract?uniplatform=NZKPT&languag)
[3] 刘玉振,刘苏婧,张志超.大学生方程式赛车车架优化设计[J].农业装备与车辆工程,2025,63(04):72-75. (https://kns.cnki.net/kcms2/article/abstract?uniplatform=NZKPT&languag)
[4] 詹士成,周钊,袁宝文,等.电机悬置支架的模态性能和轻量化优化设计[J].北京汽车,2024,(02):1-6. (https://kns.cnki.net/kcms2/article/abstract?uniplatform=NZKPT&languag)
[5] 唐志军,何欣荣. 基于STM32单片机的智能小车设计[J].电子制作,2024,32(01):36-41. (https://kns.cnki.net/kcms2/article/abstract?uniplatform=NZKPT&languag)
[6] 于子涵,郭颖,郭志彬,等. 基于STM32F103的脑控小车设计[J].电子制作,2024,32(16):35-39. (https://kns.cnki.net/kcms2/article/abstract?uniplatform=NZKPT&languag)
[7] 关志艳. 基于HC-05的小车跟随行驶系统的设计与实现[J].山西电子技术,2025,(01):7-9+44. (https://kns.cnki.net/kcms2/article/abstract?uniplatform=NZKPT&languag)
[8] 盛梓轩,康姝,张龙辉,等. 基于STM32的导盲智能小车的设计[J].现代信息科技,2025,9(19):6-10+15. (https://kns.cnki.net/kcms2/article/abstract?uniplatform=NZKPT&languag)

[^1] 图二源自https://e.tb.cn/h.7Sf09EYui7uuSBy?tk=ukEgU0DwWqa

《可行性分析报告》溯洄（宁波）智能科技有限公司

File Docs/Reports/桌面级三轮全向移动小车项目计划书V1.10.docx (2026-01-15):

# 桌面级三轮全向移动小车 项目计划书

编写： | 朱思源、覃钰莹、黄敏
审核：
日期： | 2026年1月5日
负责人： | 朱思源

目录

# 1. 简介

## 1.1. 项目背景：

目前市面上常见的入门级蓝牙小车（如淘宝通用套件）普遍存在以下痛点：

(1) 工程化程度低：硬件集成粗糙，常采用裸露的“飞线”连接方式，线束杂乱且缺乏基本的捆扎与应力释放设计。这导致在运动或振动中连接器易松动、线材易疲劳断裂，供电与信号稳定性差，整体结构脆弱，故障率高。
(2) 软件架构缺失：配套代码多为单一文件的顺序“面条式”堆砌，硬件驱动、控制逻辑与用户交互高度耦合。缺乏清晰的分层（如驱动层、算法层、应用层）与模块化设计，导致代码可读性差、功能复用困难，任何修改都可能引发意外问题，严重阻碍二次开发与教学深化。
(3) 用户体验粗糙：往往仅提供最基础的遥控功能，缺乏运行状态提示（如电量、实时速度、连接状态）等直观反馈。外观多为开放式裸板或简易亚克力叠层，缺乏一体化封装与人性化设计，使得产品显得廉价、不稳固，且操作互动感薄弱。
(4) 基于公司对新人的培养要求，本项目组计划以“三轮差速底盘”为核心载体，不追求车体体积的盲目扩大，而是追求单位体积内的技术密度与工艺完成度。我们将挑战在有限的尺寸内，实现稳定的直线循迹、丝滑的蓝牙操控以及极具科技感的外观封装。

## 1.2. 项目目的：

本项目旨在设计并研发一款具备工业级研发标准的桌面级三轮全向移动小车（Micro-AGV）。本报告的编写目的在于：

(1) 验证标准化研发流程（SOP）：借此项目跑通从需求分析、GitHub版本管理、PCB集成设计到结构堆叠的全套正规军研发流程，摒弃“飞线+胶带”的作坊式开发。
(2) 建立技术基线：针对三轮底盘的运动学特性，验证PID闭环控制算法与蓝牙通信协议的可靠性，为后续更复杂的自动化项目积累底层驱动库。
(3) 产品化尝试：在通用裸机底盘的基础上，通过工业设计赋予其完整的外观防护与交互逻辑，探索从“功能原型”向“交付级产品”跨越的可行性。

## 1.3. 参考文献：

[1] 解铁陶。基于STM32单片机的巡检机器人自动避障控制方法[J].工业控制计算机，2025,38(11):160-162+167. (https://kns.cnki.net/kcms2/article/abstract?uniplatform=NZKPT&language=CHS)
[2] 盛梓轩,康姝,张龙辉,等. 基于STM32的导盲智能小车的设计[J].现代信息科技,2025,9(19):6-10+15. (https://kns.cnki.net/kcms2/article/abstract?uniplatform=NZKPT&languag)
[3] 关志艳. 基于HC-05的小车跟随行驶系统的设计与实现[J].山西电子技术,2025,(01):7-9+44. (https://kns.cnki.net/kcms2/article/abstract?uniplatform=NZKPT&languag)
[4] 于子涵,郭颖,郭志彬,等. 基于STM32F103的脑控小车设计[J].电子制作,2024,32(16):35-39. (https://kns.cnki.net/kcms2/article/abstract?uniplatform=NZKPT&languag)
[5] 唐志军,何欣荣. 基于STM32单片机的智能小车设计[J].电子制作,2024,32(01):36-41. (https://kns.cnki.net/kcms2/article/abstract?uniplatform=NZKPT&languag)
[6] 潘良,佘小明,傅川,等.小型通用轮式电动底盘设计与试验[J].农机化研究,2023,45(09):240-244. (https://kns.cnki.net/kcms2/article/abstract?uniplatform=NZKPT&languag)
[7] 刘玉振,刘苏婧,张志超.大学生方程式赛车车架优化设计[J].农业装备与车辆工程,2025,63(04):72-75. (https://kns.cnki.net/kcms2/article/abstract?uniplatform=NZKPT&languag)
[8] 詹士成,周钊,袁宝文,等.电机悬置支架的模态性能和轻量化优化设计[J].北京汽车,2024,(02):1-6. (https://kns.cnki.net/kcms2/article/abstract?uniplatform=NZKPT&languag)

# 2. 技术路线

## 2.1. 软件：

### 2.1.1. 软件框架：

本项目摒弃传统的“前后台”裸机开发模式，采用分层解耦设计思想，将系统划分为三层：

(1) 硬件抽象层(BSP/HAL)：基于STM32CubeMX生成的HAL库，封装GPIO、PWM、UART、Timer等底层外设，屏蔽硬件差异，提高代码移植性。
(2) 核心算法层：独立封装运动控制算法库，包含增量式PID控制器、运动学解算器及通信协议解析栈。
(3) 应用逻辑层：基于有限状态机(FSM)管理系统状态（待机/遥控/故障/急停），实现业务逻辑与底层驱动的完全解耦。

### 2.1.2. 核心控制算法：

#### 2.1.2.1. PID控制与动态补偿数值补偿：

针对直流减速电机的迟滞特性，本项目采用增量式PID(Incremental PID)算法。相比位置式PID，增量式算法仅输出PWM的变化量，对计算误差累积不敏感，且在系统受到严重干扰（如电机堵转）时，能有效防止积分饱和导致的“飞车”现象。

#### 2.1.2.2. 动态补偿：

(1) 死区补偿(Dead-Zone Compensation)：针对低廉直流电机在低占空比下无法启动的物理特性，我们在软件中引入死区补偿机制。通过实验测定电机的最小启动PWM阈值，在输出端叠加基础偏置电压，消除低速下的非线性响应，确保小车能以极低速度（如5cm/s）稳定爬行。
(2) 电压前馈补偿(Voltage Feedforward)：考虑到锂电池电压随电量消耗而下降，导致相同PWM下电机转速变慢。系统实时采集电池电压，动态调整PWM输出系数，确保满电与亏电状态下动力响应一致。

#### 2.1.2.3. 运动轨迹规划：

(1) 梯形加减速算法：为了避免电机直接全速启动带来的电流冲击和机械结构（3D打印件）的应力损伤，我们引入梯形速度规划。在目标速度发生突变时，通过插值算法使速度呈线性平滑过渡，实现“软启动”与“软停止”，提升运动平稳性。
(2) 差速同步策略：针对左右电机物理特性差异导致的跑偏问题，建立双闭环耦合控制模型。当检测到一侧车轮滞后时，不仅增加该侧油门，同时微调另一侧速度，确保双轮转速比严格符合运动学模型。

### 2.1.3. 通信系统：

鉴于蓝牙通信环境存在干扰，本项目未使用CAN总线，而是设计了一套高可靠性的定长帧通信协议：

(1) 帧结构设计：采用0xA5帧头同步、功能字指令区分、数据段载荷传输、SumCheck和校验、0x5A帧尾结束的工业级格式。
(2) 状态机解析：接收端通过状态机（Wait_Header->Rx_Body->Checksum）进行数据包解析，有效过滤通信噪声，拒绝执行残缺或错误指令。

### 2.1.4. 状态监控与保护：

#### 2.1.4.1. 实时诊断系统：

系统利用SysTick定时器建立10ms时间片轮询机制，实时监控以下关键指标：

(1) 电池电压（ADC采样）
(2) 电机连接状态（编码器脉冲反馈）
(3) 通信链路心跳

#### 2.1.4.2. 故障处理：

(1) 通信失败：心跳包机制，启用看门狗逻辑，若连续500ms未收到上位机（手机端）的心跳包或控制指令，系统自动判定为“通信丢失”，强制切断电机PWM输出，触发自动急停，防止车辆失控。
(2) 数据错误：当校验和（Checksum）计算不匹配时，丢弃当前数据包并请求重发（或保持上一帧状态），防止因误码导致的误动作。
(3) 低压保护：当检测到电池电压低于6.8V时，系统进入“低功耗保护模式”，禁止电机启动并闪烁LED报警，防止锂电池过放损坏。

## 2.2. 硬件：

### 2.2.1. 电源：

使用两个18650串联锂电池作为电源。为本项目提供紧凑、高能量密度的动力源。两节串联输出7.4V标称电压，完美匹配电机驱动模块（TB6612FNG）的VM输入电压需求（4.5-13.5V），同时其较大的容量能为电机瞬态大电流提供支撑，有效减少主控因电压骤降而意外重启的风险，保障小车持续运行。

### 2.2.2. 电机驱动：

TB6612FNG本项目的动力控制核心。其MOSFET架构的高效率（＞90%）使得7.4V电池能量最大限度用于驱动，而非转化为热量，显著延长续航。关键优势在于其逻辑电压（VCC）兼容3.3V，可与STM32 GPIO直接连接，无需电平转换。内置的过热与短路保护为调试期的电机堵转或接线错误提供了安全缓冲，极大降低烧毁风险。

### 2.2.3. 蓝牙通信：

HC-05作为本项目与手机APP的无线控制链路，其经典蓝牙协议提供稳定、低延迟的串口透传，确保遥控指令实时响应。主从一体模式的灵活性远超HC-06，未来可轻松升级代码，实现小车主动连接手机（跟随模式）或双车互联等高级功能。独立的STATE连接状态引脚可接入STM32，实现“蓝牙断开则自动停车”的安全逻辑。

### 2.2.4. 主控模块：

STM32F103C8T6本项目的“大脑”，在性价比与性能间取得绝佳平衡。丰富的定时器资源可同时产生多路高频PWM（用于TB6612速度控制）并读取编码器信号（若使用编码电机）。充足的GPIO和UART接口为驱动、蓝牙、传感器等外设提供便捷连接。其3.3V逻辑电平与TB6612（VCC接3.3V）、HC-05（3.3V版本）天然兼容，简化了电路设计。

### 2.2.5. 自动升降压稳压电源模块：

s08本项目的能源枢纽，完美解决了单电池组供电的核心难题。它能将波动剧烈的锂电池电压（充满8.4V至放空约6.0V）智能且稳定地转换为系统所需的5V和3.3V。相比使用独立的降压模块，S08一体化方案简化了布线，减少了空间占用，并确保了在整个电池放电周期内，主控、蓝牙、传感器都能获得稳定电压，系统可靠性大幅提升。

### 2.2.6. 洞洞板：

项目开发与原型验证阶段的绝佳平台。其灵活性允许快速搭建和修改电路，非常适合连接STM32、TB6612、S08等模块进行功能调试和逻辑验证。是测试电源方案、驱动逻辑和蓝牙通信的低成本、高效率实验载体，为后续设计定制PCB提供可靠的电路基础。

### 2.2.7. PCB：

项目迭代与成品的终极形态。将基于洞洞板验证成功的电路转化为定制PCB，能实现高度集成、布线优化和可靠连接。消除飞线，提升抗干扰能力，使小车结构更紧凑、更专业。是项目从“实验原型”迈向“稳定作品”的关键一步。

## 2.3. 结构：

### 2.3.1. 小车运动性能数据指标

#### 2.3.1.1. 驱动力矩

基于整车设计总重550g、驱动轮直径64mm、模拟地面摩擦系数0.02以及目标启动加速度0.5m/s²计算得出，启动所需的最小力矩计算公式为：
T总=m(gμ+a)×r≈0.012T总=m(gμ+a)×r≈0.012

#### 2.3.1.2. 行驶速度

小车速度过快不易精确操控，过慢则响应迟钝。经综合评估，设定额定巡航速度≥0.3m/s（约合1.08km/h）为顶层设计目标，旨在平衡桌面级平台的操作响应性与运动可控性。基于此速度与选定的64mm轮胎，可反推出轮组的转速要求：
n轮组需求=v/πD×60=0.3/（3.14×0.064）×60≈90 r/min

### 2.3.2. 结构概型

#### 2.1.2.1. 整车结构

蓝牙小车采用工业风箱体式整体造型，线条简洁，几何轮廓规整。上壳顶部嵌入一块透明视窗，能通过透明区域直观看到内部元件布局；装饰条与上壳一体化，底盘和外围一体化为车厢主体。上壳与车厢主体用螺栓连接，建模无多余拼接缝隙。行走系统采用双主动轮+单万向轮的经典布局，主动轮对称分布于车身两侧，万向轮置于尾部，轮组与车身底板的连接位设计紧凑，与箱体造型形成协调的比例关系。


图1小车模型

#### 2.1.2.4. 底盘部分

底盘部分由一块自开孔底板和2个JGB25-370直流减速电机构成，由电机输出轴+联轴器+螺丝锁紧进行连接，电机的固定双支座悬梁式安装方案，能有效约束电机在各方向的位移与振动，保证其在高负载工况下的定位精度与运行平稳性。

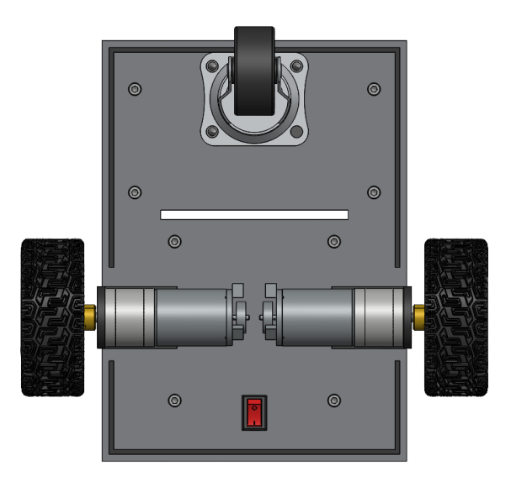
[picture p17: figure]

图2小车底盘

#### 2.1.2.5. 底盘布局

分区的布局策略：电池组作为重质量单元，布置于底盘低重心区域（后部）以提升稳定性；主控PCB、传感器等电子单元集中于防护性好的中部舱体内；线束通过预设通道走线，确保整洁与安全。

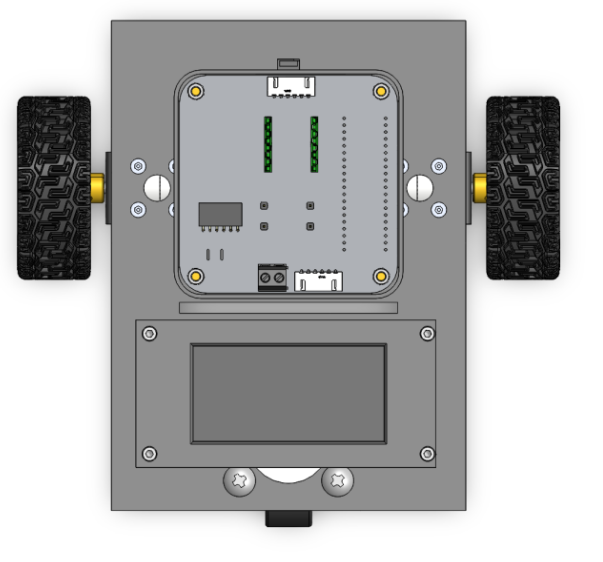
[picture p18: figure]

图3底盘布局

#### 2.1.2.6. 槽位布局

采用M3标准六角铜柱作为PCB与安装底板的机械连接件，安装底板上预设的螺纹孔阵列与PCB板上的安装过孔位置完全一致，该方式在PCB板与安装平面之间形成了稳固的机械连接和必要的散热间隙。电池包外形与底盘预留的电池舱空间完全匹配，四周留有必要安装余量。

图片包含 图形用户界面 AI 生成的内容可能不正确。

图4电池盒布局

### 2.3.3. 电机选型

#### 2.3.3.1. 负载重量估算

采用PETG材质进行3D打印，密度约1.3g/cm³，车身框架尺寸为190*138*95mm，粗略估算重量≤600g。

#### 2.3.3.2. 额定转矩匹配

在双轮正常工作的情况下，整车总驱动力矩0.012N ∙ m由两个电机共同提供。因此，单电机额定转矩需满足：
, T电机额定≥(T总)/2=0.006#（1）

#### 2.3.3.3. 额定转速匹配

为实现0.3m/s的目标巡航速度，并简化控制，应优先选用额定转速为90r/min的电机，使其直接匹配轮组转速需求：
, n电机额定≈n轮组需求=90 r/(min)#（2）

#### 2.3.3.4. 峰值转矩匹配

电机的峰值转矩能力必须覆盖单轮失效时所需承担的整车总驱动力矩，即：
, T电机峰值≥T总=0.012#（3）

#### 2.3.3.5. 电机选型

经对比，JGA25-370直流减速电机（额定扭矩0.8kg ∙ cm，峰值扭矩4.4kg ∙ cm，额定转速100r/min，减速比46.8:1）其参数与本项目需求高度匹配。其减速后100r/min的额定转速略高于9r/min的轮组需求，可通过软件调速轻松适配目标车速；其额定与峰值扭矩均远超系统最低要求十倍以上，动力储备与安全冗余充足，并且为未来增加负载留下了巨大空间。该型号为市场主流规格，性价比高，故采用。

# 3. 项目计划

## 3.1. 项目团队

表1人员安排表

职务 | 人员 | 附件
总负责人 | 朱思源
软件 | 朱思源
硬件 | 黄敏
结构 | 覃钰莹

## 3.2. 成本估计

### 3.2.1. 硬件：

表2硬件成本表

序号 | 名称 | 规格 | 单价（元） | 数量（个/套） | 运费（元） | 总价（元）
1 | 大简3D打印耗材 | PETG银色1kg | 25.59 | 2 | 0 | 51.18
2 | R3D3D打印耗材 | PETG透明色1kg | 23.9 | 1 | 0 | 23.9
3 | M3螺栓组 | M3x9mm（100粒） | 5.5 | 1 | 0 | 5.5
4 | M3螺栓组 | M3x10mm（100粒） | 5.3 | 1 | 0 | 5.3
5 | M3螺栓组 | M3x14mm（100粒） | 7.5 | 1 | 0 | 7.5
6 | M3双通铜柱 | M3x6mm（30粒） | 3.6 | 1 | 0 | 3.6
7 | M3双通铜柱 | M3x21mm（15粒） | 4.5 | 1 | 0 | 4.5
8 | M3六角铜柱 | M3×6+10mm（20粒） | 4 | 1 | 1 | 5
9 | 黑色十字扁头螺丝钉 | M3×8mm（50个） | 3.64 | 1 | 0 | 3.64
10 | M3绝缘橡胶垫 | 3×6×1mm（200个） | 2.02 | 1 | 0 | 2.02
11 | 直流电机套装 | JGA25-370电机配d65mm轮胎 | 27.8 | 2 | 6 | 61.6
12 | 万向轮 | 1.5英寸 | 3.08 | 1 | 0 | 3.08
| 总价 | | | | | 176.82

### 3.2.2. 结构：

表3结构成本表

序号 | 名称 | 单价（元） | 数量（个/套） | 运费（元） | 总价（元）
1 | TB6612FNG电机驱动板模块 (https://item.taobao.com/item.htm?id=607254624071&from=cart&skuId=5205675671358&upStreamPrice=140) | 4.8 | 3 | 0 | 14.4
2 | 18650锂电池*2加充电盒 | 27 | 1 | 0 | 27
3 | 电池盒 | 1.7 | 3 | 0 | 5.1
4 | DC-DC自动升降压稳压电源模块s08 | 5.4 | 5 | 0 | 27
5 | STM32F103C8T6 | 7.59 | 3 | 0 | 22.77
6 | HC-05 | 14.46 | 3 | 0 | 43.38
7 | xh2.54 6p | 0.0778 | 50 | 0 | 3.89
8 | 弯针排母 | 0.3 | 10 | 0 | 3
9 | 洞洞板 | 1.225 | 2 | 0 | 2.45
10 | 面包板 | 5.92 | 1 | 0 | 5.92
11 | 杜邦线 | 8.57 | 1 | 0 | 8.57
12 | 18650锂电池 | 7 | 3 | 0 | 21
| 总价 | | | | 184.48

### 3.2.3. 总计：

硬件184.48元+结构176.82元=361.3元。

申请总价：440元。

## 3.3. 进度表

表4进度表

序号 | 分工 | 任务名称 | 天数 | 开始日期 | 结束日期 | 二 | 三 | 四 | 五 | 六 | 日 | 一 | 二 | 三 | 四 | 五 | 六 | 日 | 一 | 二 | 三 | 四 | 五 | 六
| | | | | | 30 | 31 | 1 | 2 | 3 | 4 | 5 | 6 | 7 | 8 | 9 | 10 | 11 | 12 | 13 | 14 | 15 | 16 | 17
1 | | 元旦放假 | 3 | 2026/01/01 | 2026/01/03
2 | | 修改文档 | 7 | 2025/12/30 | 2026/01/05
3 | | 三个部门开始采购到确认收货 | 7 | 2026/01/06 | 2026/01/12
4 | 结构 | 建模 | 7 | 2025/12/30 | 2026/01/05
5 | | 结构打印 | 7 | 2026/01/06 | 2026/01/12
6 | | 结构组装 | 3 | 2026/01/10 | 2026/01/12
7 | | 结构测试 | 3 | 2026/01/10 | 2026/01/12
8 | 硬件 | 画PCB | 7 | 2025/12/30 | 2026/01/05
9 | | 测试PCB板 | 3 | 2026/01/06 | 2026/01/08
10 | | PCB纠错并改正 | 2 | 2026/01/08 | 2026/01/09
11 | | 重新画板并下单 | 4 | 2026/01/09 | 2026/01/12
12 | | 杜邦线面包板同步进行备用方案 | 7 | 2026/01/06 | 2026/01/12
13 | 软件 | GitHub仓库搭建 | 2 | 2025/12/30 | 2025/12/31
14 | | 软件框架搭建 | 7 | 2025/12/30 | 2026/01/05
15 | | 学习电机控制 | 2 | 2026/01/06 | 2026/01/07
16 | | 锻件驱动配置 | 2 | 2026/01/08 | 2026/01/09
17 | | 编写协议栈代码 | 2 | 2026/01/10 | 2026/01/11
18 | | 借用公司编码电机编写PID | 2 | 2026/01/12 | 2026/01/13
19 | | 软件调试参数 | 3 | 2026/01/14 | 2026/01/16
20 | | 验收 | 1 | 2026/01/17 | 2026/01/17

表4进度表续表

# 4. 项目验收标准

该项目的最终验收标准是：

(1) 运动精度（核心）：
    i. 及格线：按住控制按钮小车可以始终执行操作，且向前行驶2米偏离不超过30cm。
    ii. 挑战线：开启PID闭环控制后，直线行驶2米偏离不超过15cm。
(2) 交互延迟：手机发送指令到车轮响应，延迟低于100ms（肉眼无明显滞后感）。
(3) 续航能力：在50%PWM巡航速度、空载工况下，连续运行时间>7分钟。
(4) 通信稳定性：有效控制距离>5米，且在断连发生时具备自动急停功能。
(5) 代码规范：0警告（0Warning，0Error），核心函数注释覆盖率>75%。
(6) 结构完整性：车辆跌落（离地10cm零速掉落）后，外壳不散架，电池不脱落，电路不断连。

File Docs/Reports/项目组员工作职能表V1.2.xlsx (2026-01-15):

项目组员工作职能表
项目名称： | 桌面级三轮全向移动小车（Micro-AGV） |  |  | 开工日期： | 2025/12/xx
岗位名称 | 项目发起人 | 项目负责人 | 结构工程师 | 硬件工程师 | 软件工程师
员工姓名 | 朱思源 | 朱思源 | 覃钰莹 | 黄敏 | 朱思源
联系方式 | 15924303822 | 15924303822 | 17377282569 | 13065827619 | 15924303822
岗位名称 | 岗位职能
项目发起人 | 1.项目关口的核心决策：提出项目愿景、目标和核心需求，明确项目价值与战略意义；2.资源保障：协调组织内外部资源，为项目提供支持并扫清关键障碍；3.方向把控：审批项目重大节点，包括但不限于范围变更、预算调整等，确保项目符合整体战略方向，最终对项目成败负责
项目负责人 | 1.全流程统筹：制定项目计划，跟踪执行进度，协调跨部门写作，解决项目中的冲突与问题；2.成本与采购管理：负责项目预算编制与控制，对接软硬件物料采购、供应商筛选，确保成本可控且供应链顺畅；3.运营维护：牵头制定项目落地后运维方案，协调后期运营维护工作，监督技术文档资料的整理归档，确保文档完整性；4.风险管控：识别项目风险，制定应对措施，向项目发起人汇报项目进展
结构工程师 | 1.结构方案设计：根据需求进行机械结构设计，完成3D建模、2D工程图输出、公差分析与标注以及材料选型，确保结构方案满足功能需求；2.原型的制作与测试：主导或参与结构原型的制作跟进，执行结构相关的功能测试、环境测试、寿命测试及可靠性验证，确保产品结构满足设计规范和标准；3.协同硬件工程师进行元器件布局，确保产品顺利生产和组装。
硬件工程师 | 1.硬件方案设计：根据架构要求，设计硬件电路、选型元器件，确保硬件性能满足功能需求；2.原型开发与调试：制作硬件原型，进行硬件测试，解决硬件故障；3.跨团队协作：配合软件工程师确认硬件与控制逻辑的适配性，提供物料清单，协助优化硬件结构；4.与结构衔接
软件工程师 | 1.嵌入式软件：根据需求应用项目所需的应用软件，实现硬件设备的底层控制逻辑；2.调试优化:测试嵌入式代码控制的可靠性，解决控制逻辑中的bug
备注

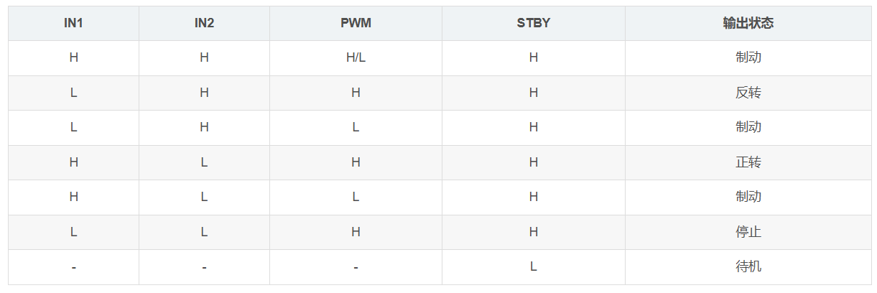
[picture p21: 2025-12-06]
Docs/Datasheets/电机驱动详情/真值表.png

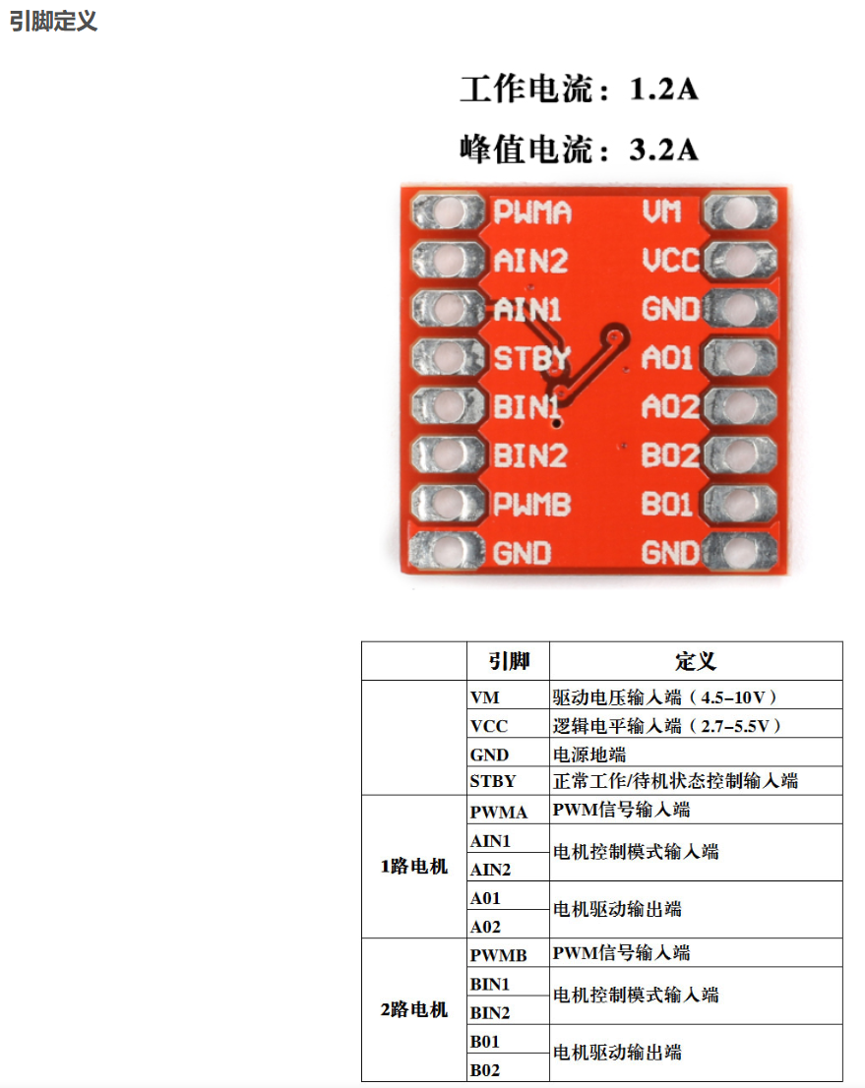
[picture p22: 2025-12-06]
Docs/Datasheets/电机驱动详情/引脚定义.png

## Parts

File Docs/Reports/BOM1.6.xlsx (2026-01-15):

Ebom of Bluetooth car（Bluetooth car N1.3)
Document Number : |  | Ebom-Fourier N1-V1.4 | Edit by： |  |  |  | 朱思源、覃钰莹、黄敏 | Date： | 2025.12.24
Version： |  | V1.4 | Review by： |  |  |  | 何勇 | Date： | 2025.12.24
Product Model: |  |  | Approval by： |  |  |  |  | Date： | 2025.12.24
Number | Part Name | specification | Quantity | Unit | Version | price | Remark | Classification | link URL
结构件
1 | M3螺栓组 | M3X10mm（100套） | 1 | pack | NA | 5.3 | 连接底板和电池仓、PCB槽铜柱紧固 | 标准件 | https://detail.tmall.com/item.htm?from=cart&id=635755541429&skuId=6147493403016&upStreamPrice=346
2 | M3螺栓组 | M3X9mm（100套） | 1 | pack | NA | 5.5 | 连接底板和电机支架 | 标准件 | https://detail.tmall.com/item.htm?from=cart&id=636950471592&skuId=5969685766429&upStreamPrice=364
3 | M3螺栓组 | M3X14mm（100套） | 1 | pack | NA | 7.5 | 固定连接车厢和后挡板的铜柱 | 标准件 | https://detail.tmall.com/item.htm?from=cart&id=636427093923&skuId=5844339057370&upStreamPrice=460
4 | 双通铜柱 | M3×6mm（30粒） | 1 | pack | NA | 3.6 | 连接车厢和后挡板 | 标准件 | https://detail.tmall.com/item.htm?from=cart&id=542213588710&skuId=5060329971212&upStreamPrice=217
5 | 黑色十字扁平头螺丝钉 | M3×8mm（50粒） | 1 | pack | NA | 3.64 | 连接车厢和上壳 | 标准件 | https://detail.tmall.com/item.htm?from=cart&id=818971657238&skuId=5691735427069&upStreamPrice=120
6 | 双通铜柱 | M3×21mm（15粒） | 1 | pack | NA | 4.5 | 连接电池仓底面和顶板 | 标准件 | https://detail.tmall.com/item.htm?from=cart&id=542213588710&skuId=5782903840982&upStreamPrice=296
7 | M3六角铜柱 | M3×6+10mm（20粒） | 1 | pack | NA | 5 | 连接底板和PCB板和PCB槽 | 标准件 | https://detail.tmall.com/item.htm?from=cart&id=19634185206&skuId=4812159197311&upStreamPrice=200
8 | M3绝缘橡胶垫 | 3×6×1mm（200粒） | 1 | pack | NA | 2.02 | PCB绝缘与防松辅助 | 标准件 | https://detail.tmall.com/item.htm?from=cart&id=38159274251&skuId=45131585922&upStreamPrice=78
9 | 直流减速电机套件（含支架与65mm轮胎） | 6V 130RPM/min PH2.0转xH2.54端子线 | 2 | set | NA | 61.6 | 于底盘下方提供驱动扭矩，实现小车直线与转向运动 | 标准件 | https://item.taobao.com/item.htm?from=cart&id=860025006963&skuId=5937605271350&upStreamPrice=2257
10 | 万向轮 | 1.5英寸 安装高度53mm | 1 | pcs | NA | 3.08 | 于底盘下方承受后部载荷 | 标准件 | https://item.taobao.com/item.htm?from=cart&id=944436764770&skuId=6011443082883&upStreamPrice=308
11 | 大简3D打印耗材 | PETG银色 1kg | 2 | kg | NA | 51.18 | 打印车身 | 原材料 | https://detail.tmall.com/item.htm?from=cart&id=944008246964&skuId=5927683612934&upStreamPrice=2069
12 | R3D3D打印耗材 | PETG透明色 1kg | 1 | kg | NA | 23.9 | 打印上壳视窗 | 原材料 | https://detail.tmall.com/item.htm?from=cart&id=750164175683&skuId=5461047058649&upStreamPrice=2267
电气元件
1 | TB6612FNG电机驱动板模块 | TB6612FNG电机驱动焊好排针 | 3 | pcs | V1.0 | 14.4 | 接收核心板信号，驱动小车电机正反转、调速 | 电机驱动模块 | https://item.taobao.com/item.htm?from=cart&id=607254624071&skuId=5205675671358&upStreamPrice=480
2 | 18650锂电池*2加充电盒 | 2节5550mwh尖头【送智能充电器】 | 1 | set | NA | 27 | 为锂电池充电，备用电池供电 | 储能套件 | https://detail.tmall.com/item.htm?from=cart&id=664521581992&skuId=5968805259620&upStreamPrice=1760
3 | 电池盒 | 18650 2节 带盖带开关（串联） | 3 | set | NA | 5.1 | 固定锂电池，为小车整体供电 | 电池配件 | https://item.taobao.com/item.htm?from=cart&id=521721340756&skuId=4242266569920&upStreamPrice=170
4 | DC-DC自动升降压稳压电源模块s08 | S08进口芯片-5V | 5 | pcs | V1.2 | 27 | 稳定输出电压，为核心板和电机驱动供电 | 电源模块 | https://detail.tmall.com/item.htm?from=cart&id=651615356988&skuId=4707016125192&upStreamPrice=535
5 | STM32F103C8T6核心板 | 国产_STM32F103C8T6_Type-C_焊接 | 3 | pcs | V1.0 | 22.77 | 小车控制中枢，处理指令、输出控制信号 | 主控核心模块 | https://item.taobao.com/item.htm?from=cart&id=946102518580&skuId=5854281617647&upStreamPrice=759
6 | HC-05蓝牙模块 | HC-05蓝牙模块 带底板焊排针 兼容版 | 3 | pcs | V2.0 | 43.38 | 接收上位机指令，传输给核心板 | 无线通信模块 | https://detail.tmall.com/item.htm?from=cart&id=722740857813&skuId=5027572309332&upStreamPrice=1266
7 | 弯针插座 | 6P 2.54mm弯针（50个） | 50 | pcs | NA | 3.89 | 核心板与驱动板、电源模块的信号转接 | 连接器 | https://detail.tmall.com/item.htm?from=cart&id=609069698010&skuId=4450119279590&upStreamPrice=386
8 | 弯针排母 | 6P 单排母弯针（10个） | 10 | pcs | NA | 3 | 焊接在洞洞板，扩展核心板 IO 接口 | 连接器 | https://detail.tmall.com/item.htm?from=cart&id=660775265911&skuId=4768989725198&upStreamPrice=300
9 | 洞洞板 | 绿油 单面 6x8CM 环氧板 2张 | 2 | pcs | NA | 2.45 | 搭建临时电路，焊接排母、转接元件 | 实验耗材 | https://detail.tmall.com/item.htm?from=cart&id=17952641393&skuId=4097467399887&upStreamPrice=214
10 | 面包板 | 面包板 实验板 830孔 1个 | 1 | pcs | NA | 5.92 | 免焊搭建电路，测试模块连接与功能 | 实验耗材 | https://detail.tmall.com/item.htm?from=cart&id=16513870165&skuId=3975401538352&upStreamPrice=587
11 | 杜邦线 | 【划算款】杜邦线15cm母对母+公对母+公对公 共120根 | 1 | pcs | NA | 8.57 | 模块间、核心板与面包板的信号连接 | 连接线材 | https://detail.tmall.com/item.htm?from=cart&id=14466195609&skuId=5922240227955&upStreamPrice=722
12 | 18650锂电池 | 2节5550mwh尖头【送同款一节】 | 3 | pcs | NA | 21 | 小车电池，为系统供电 | 储能元件 | https://detail.tmall.com/item.htm?from=cart&id=664521581992&skuId=5968805259618&upStreamPrice=1280
13 | Total Price |  |  |  |  |  | 361.3 | 无
14 | Recommended Total |  |  |  |  |  | 440 | 安全冗余

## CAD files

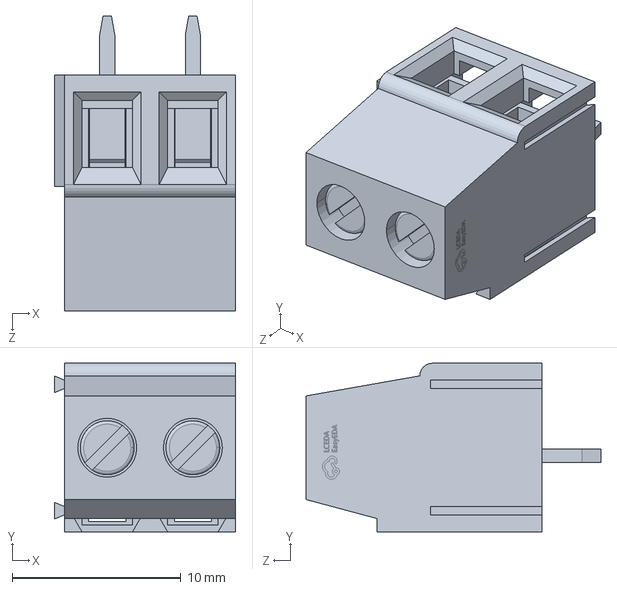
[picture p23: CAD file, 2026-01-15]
Mechanical/小车装配体/P1~CONN-TH_2P-P5.00_WJ500V-5.08-2P~CONN-TH_2P-P5.00_WJ500V-5.08-2P~YOpK.SLDASM
10.8 x 10.00 x 17.5 mm

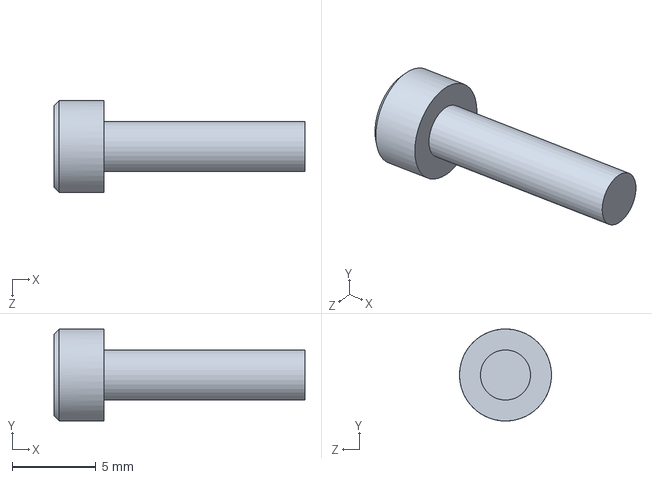
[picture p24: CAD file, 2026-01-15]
Mechanical/小车装配体/M3×12螺栓.SLDPRT
15.0 x 5.50 x 5.50 mm

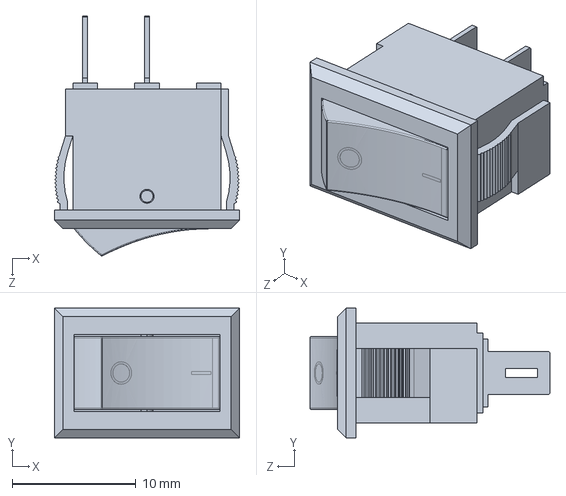
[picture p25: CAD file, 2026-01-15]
Mechanical/小车装配体/SW-TH_2P-L15.0-W10.5-P5.00_KCD11-2P-R~SW-TH_2P-L15.0-W10.5-P5.00_KCD11-2P-R~YOpK.SLDPRT
15.0 x 10.5 x 19.4 mm

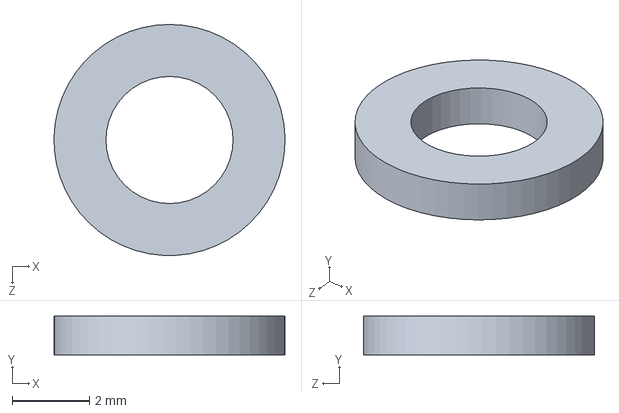
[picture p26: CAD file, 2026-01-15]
Mechanical/小车装配体/绝缘橡胶垫.SLDPRT
6.00 x 1.00 x 6.00 mm

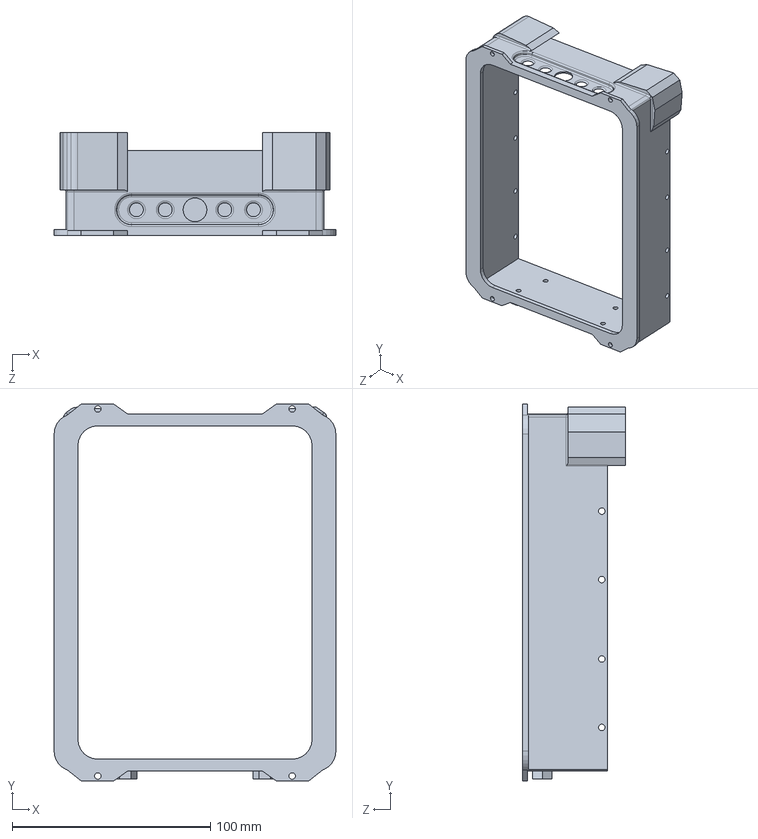
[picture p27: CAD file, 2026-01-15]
Mechanical/小车装配体/车厢.SLDPRT
142.0 x 190.0 x 52.0 mm

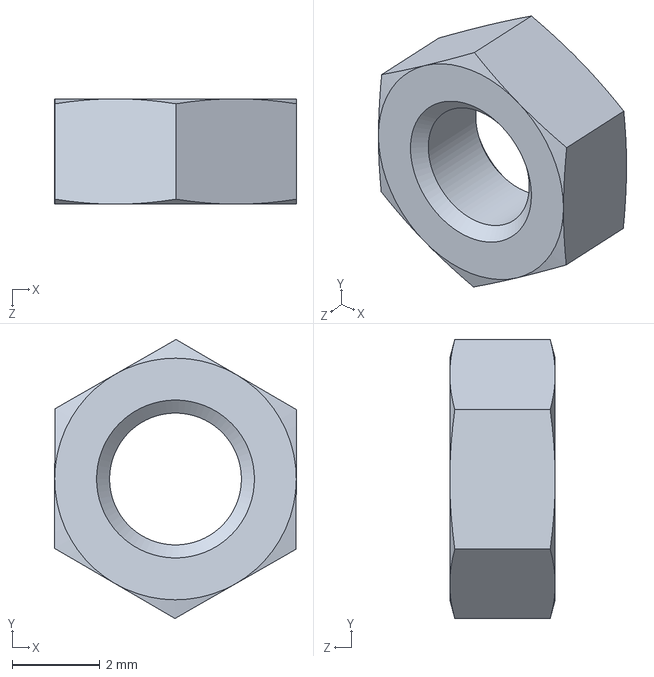
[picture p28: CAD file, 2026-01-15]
Mechanical/小车装配体/m3螺母。.SLDPRT
5.51 x 6.35 x 2.40 mm

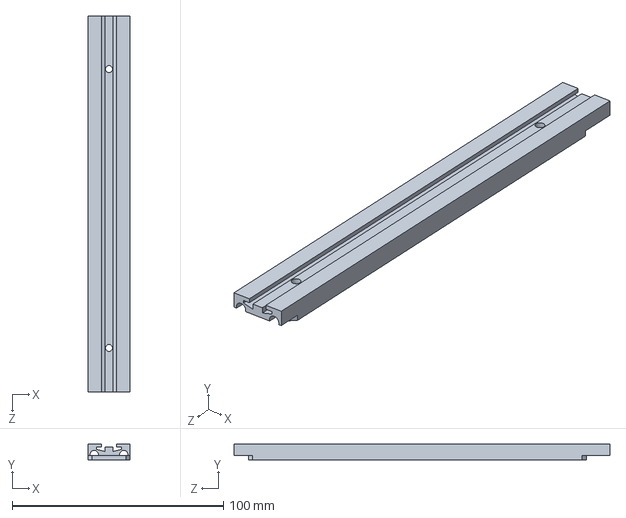
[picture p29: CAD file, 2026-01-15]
Mechanical/小车装配体/头饰-左.SLDPRT
20.0 x 7.50 x 178.0 mm

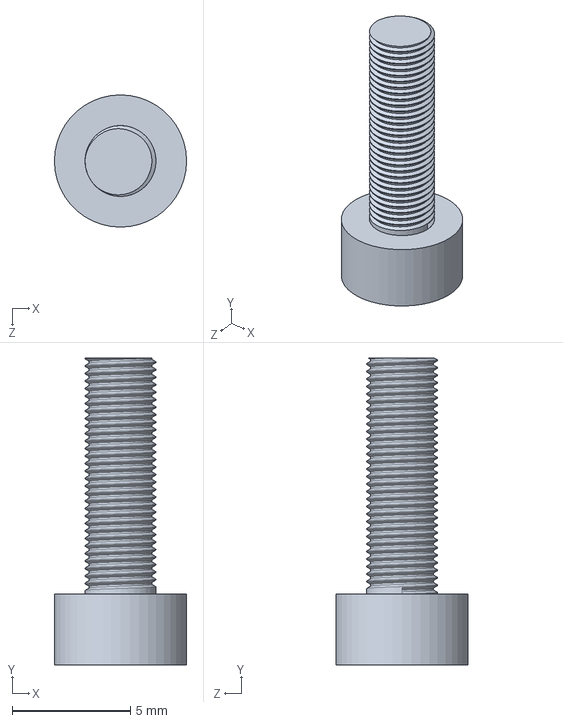
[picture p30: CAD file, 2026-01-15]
Mechanical/小车装配体/M3×10螺丝自创.SLDPRT
5.60 x 13.0 x 5.60 mm

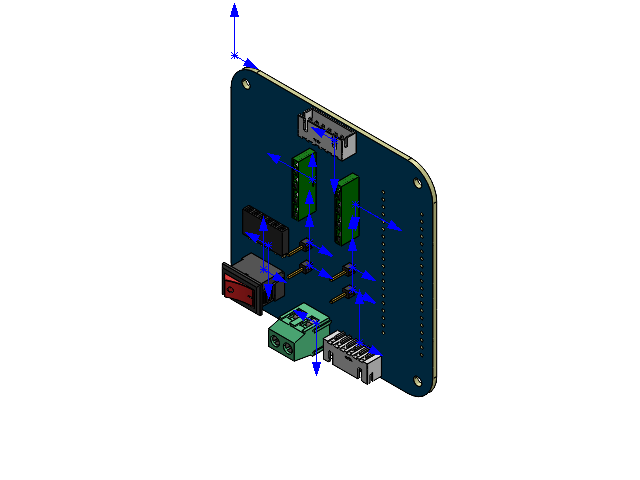
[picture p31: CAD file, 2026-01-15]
Mechanical/小车装配体/小车板.SLDASM
CONN-TH_2P-P5.00_WJ500V-5.08-2P~CONN-TH_2P-P5.00_WJ500V-5.08-2P~YOpK
CONN-TH_6P-P2.50_ZX-XH2.54-6PWZ~CONN-TH_6P-P2.50_ZX-XH2.54-6PWZ~YOpK x 2
HDR-TH_1P-P2.54-V-M~HDR2.54-M-LI-1X1P~YOpK x 4
HDR-TH_6P-P2.54-H-F-W10.2~HDR-TH_6P-P2.54-H-F-W10.2~YOpK
HDR-TH_8P-P2.54-V-F_2~HDR-TH_8P-P2.54-V-F_2~YOpK x 2
Board~YOpK

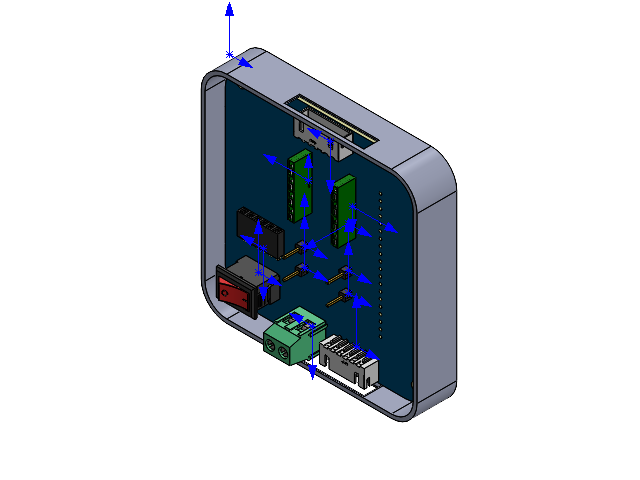
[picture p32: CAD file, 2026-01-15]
Mechanical/小车装配体/PCB实板加板框.SLDASM
CONN-TH_2P-P5.00_WJ500V-5.08-2P~CONN-TH_2P-P5.00_WJ500V-5.08-2P~YOpK
CONN-TH_6P-P2.50_ZX-XH2.54-6PWZ~CONN-TH_6P-P2.50_ZX-XH2.54-6PWZ~YOpK x 2
HDR-TH_1P-P2.54-V-M~HDR2.54-M-LI-1X1P~YOpK x 4
HDR-TH_6P-P2.54-H-F-W10.2~HDR-TH_6P-P2.54-H-F-W10.2~YOpK
HDR-TH_8P-P2.54-V-F_2~HDR-TH_8P-P2.54-V-F_2~YOpK x 2
Board~YOpK
PCB壳子

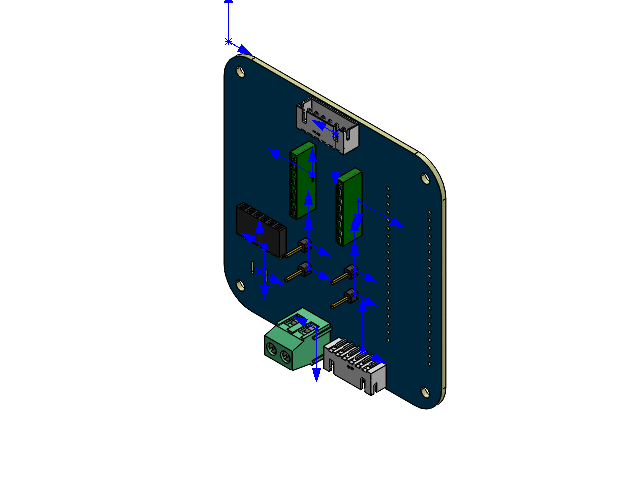
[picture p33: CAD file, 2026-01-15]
Mechanical/小车装配体/PCB实板.SLDASM
CONN-TH_2P-P5.00_WJ500V-5.08-2P~CONN-TH_2P-P5.00_WJ500V-5.08-2P~YOpK
CONN-TH_6P-P2.50_ZX-XH2.54-6PWZ~CONN-TH_6P-P2.50_ZX-XH2.54-6PWZ~YOpK x 2
HDR-TH_1P-P2.54-V-M~HDR2.54-M-LI-1X1P~YOpK x 4
HDR-TH_6P-P2.54-H-F-W10.2~HDR-TH_6P-P2.54-H-F-W10.2~YOpK
HDR-TH_8P-P2.54-V-F_2~HDR-TH_8P-P2.54-V-F_2~YOpK x 2
Board~YOpK

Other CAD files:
Mechanical/小车装配体/SW1~SW-TH_2P-L15.0-W10.5-P5.00_KCD11-2P-R~SW-TH_2P-L15.0-W10.5-P5.00_KCD11-2P-R~YOpK.SLDASM
Mechanical/小车装配体/H5~HDR-TH_6P-P2.54-H-F-W10.2~HDR-TH_6P-P2.54-H-F-W10.2~YOpK.SLDASM
Mechanical/小车装配体/H1~HDR-TH_1P-P2.54-V-M~HDR2.54-M-LI-1X1P~YOpK.SLDASM
Mechanical/小车装配体/P6~HDR-TH_8P-P2.54-V-F_2~HDR-TH_8P-P2.54-V-F_2~YOpK.SLDASM
Mechanical/小车装配体/U5~CONN-TH_6P-P2.50_ZX-XH2.54-6PWZ~CONN-TH_6P-P2.50_ZX-XH2.54-6PWZ~YOpK.SLDASM
Mechanical/小车装配体/CONN-TH_2P-P5.00_WJ500V-5.08-2P~CONN-TH_2P-P5.00_WJ500V-5.08-2P~YOpK.SLDPRT
Mechanical/小车装配体/头饰-右.SLDPRT
Mechanical/小车装配体/Board~YOpK.SLDPRT
Mechanical/小车装配体/CONN-TH_6P-P2.50_ZX-XH2.54-6PWZ~CONN-TH_6P-P2.50_ZX-XH2.54-6PWZ~YOpK.SLDPRT
Mechanical/小车装配体/HDR-TH_1P-P2.54-V-M~HDR2.54-M-LI-1X1P~YOpK.SLDPRT
Mechanical/小车装配体/HDR-TH_6P-P2.54-H-F-W10.2~HDR-TH_6P-P2.54-H-F-W10.2~YOpK.SLDPRT
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

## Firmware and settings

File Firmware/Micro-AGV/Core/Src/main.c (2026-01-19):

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
/* Includes ------------------------------------------------------------------*/
#include "main.h"

/* USER CODE BEGIN Includes */
#include <math.h>
#include <stdlib.h> // 用于 abs() 函数
#include <string.h>

/* USER CODE END Includes */

TIM_HandleTypeDef htim2;
TIM_HandleTypeDef htim3;
TIM_HandleTypeDef htim4;

UART_HandleTypeDef huart1;

void SystemClock_Config(void);
static void MX_GPIO_Init(void);
static void MX_TIM2_Init(void);
static void MX_USART1_UART_Init(void);
static void MX_TIM3_Init(void);
static void MX_TIM4_Init(void);
/* USER CODE BEGIN PFP */
void Control_Loop(void);
void Set_Motor_Speed(int speed_L, int speed_R);
/* USER CODE END PFP */

/* USER CODE BEGIN 0 */

// --- 硬件调试参数 ---
// 如果发现轮子转动方向相反，或者 PID 导致飞车（正反馈），将对应的 1 改为 -1
#define MOTOR_L_POLARITY 1
#define MOTOR_R_POLARITY 1

// --- 电机引脚控制宏 ---
#define MOTOR_L_FWD()                                                          \
  {                                                                            \
    HAL_GPIO_WritePin(L_IN1_GPIO_Port, L_IN1_Pin, 1);                          \
    HAL_GPIO_WritePin(L_IN2_GPIO_Port, L_IN2_Pin, 0);                          \
  }
#define MOTOR_L_BWD()                                                          \
  {                                                                            \
    HAL_GPIO_WritePin(L_IN1_GPIO_Port, L_IN1_Pin, 0);                          \
    HAL_GPIO_WritePin(L_IN2_GPIO_Port, L_IN2_Pin, 1);                          \
  }
#define MOTOR_L_STOP()                                                         \
  {                                                                            \
    HAL_GPIO_WritePin(L_IN1_GPIO_Port, L_IN1_Pin, 0);                          \
    HAL_GPIO_WritePin(L_IN2_GPIO_Port, L_IN2_Pin, 0);                          \
  }

#define MOTOR_R_FWD()                                                          \
  {                                                                            \
    HAL_GPIO_WritePin(R_IN1_GPIO_Port, R_IN1_Pin, 1);                          \
    HAL_GPIO_WritePin(R_IN2_GPIO_Port, R_IN2_Pin, 0);                          \
  }
#define MOTOR_R_BWD()                                                          \
  {                                                                            \
    HAL_GPIO_WritePin(R_IN1_GPIO_Port, R_IN1_Pin, 0);                          \
    HAL_GPIO_WritePin(R_IN2_GPIO_Port, R_IN2_Pin, 1);                          \
  }
#define MOTOR_R_STOP()                                                         \
  {                                                                            \
    HAL_GPIO_WritePin(R_IN1_GPIO_Port, R_IN1_Pin, 0);                          \
    HAL_GPIO_WritePin(R_IN2_GPIO_Port, R_IN2_Pin, 0);                          \
  }

// --- PWM 与死区设置 ---
#define PWM_MAX_VALUE 1799
#define MOTOR_DEAD_ZONE 200 // 电机死区补偿值 (根据实测调整，通常 150-300)

// 设置电机速度 (输入范围: -1799 到 1799)
void Set_Motor_Speed(int pwm_L, int pwm_R) {
  // --- 左轮控制 ---
  int out_L = pwm_L;
  // 死区补偿：如果有输出，则加上死区值
  if (out_L > 0)
    out_L += MOTOR_DEAD_ZONE;
  else if (out_L < 0)
    out_L -= MOTOR_DEAD_ZONE;

  // 限幅
  if (out_L > PWM_MAX_VALUE)
    out_L = PWM_MAX_VALUE;
  if (out_L < -PWM_MAX_VALUE)
    out_L = -PWM_MAX_VALUE;

  // 驱动硬件
  if (out_L > 0)
    MOTOR_L_FWD()
  else if (out_L < 0)
    MOTOR_L_BWD()
  else
    MOTOR_L_STOP();

  __HAL_TIM_SET_COMPARE(&htim2, TIM_CHANNEL_2, abs(out_L));

  // --- 右轮控制 ---
  int out_R = pwm_R;
  if (out_R > 0)
    out_R += MOTOR_DEAD_ZONE;
  else if (out_R < 0)
    out_R -= MOTOR_DEAD_ZONE;

  if (out_R > PWM_MAX_VALUE)
    out_R = PWM_MAX_VALUE;
  if (out_R < -PWM_MAX_VALUE)
    out_R = -PWM_MAX_VALUE;

  if (out_R > 0)
    MOTOR_R_FWD()
  else if (out_R < 0)
    MOTOR_R_BWD()
  else
    MOTOR_R_STOP();

  __HAL_TIM_SET_COMPARE(&htim2, TIM_CHANNEL_1, abs(out_R));
}

// --- 物理参数 ---
#define PULSE_PER_TURN 2060.0f // 编码器每圈脉冲数
#define WHEEL_DIAMETER 0.064f  // 轮子直径 64mm
#define WHEEL_CIRCUMFERENCE (3.14159f * WHEEL_DIAMETER)
#define CONTROL_PERIOD 50 // 控制周期 50ms

// 速度转换系数: (脉冲数 -> m/s)
const float SPEED_RATIO =
    (WHEEL_CIRCUMFERENCE / PULSE_PER_TURN) * (1000.0f / CONTROL_PERIOD);

// 编码器历史值
int16_t last_count_L = 0;
int16_t last_count_R = 0;

// --- 速度控制变量 ---
// final_speed: 蓝牙下达的最终目标速度
volatile float final_speed_L = 0.0f;
volatile float final_speed_R = 0.0f;
// ramped_speed: 送给 PID 的平滑后目标速度 (解决起步猛冲)
float ramped_speed_L = 0.0f;
float ramped_speed_R = 0.0f;
// current_speed: 实际测量速度
float current_speed_L = 0.0f;
float current_speed_R = 0.0f;

// --- 平滑启动参数 ---
// 加速度限制: 每次 50ms 周期速度变化不超过 0.02m/s
// 相当于 0.4 m/s^2 的加速度，起步会很柔和
#define ACCEL_STEP 0.02f

// --- 安全看门狗 ---
uint32_t last_rx_time = 0; // 上一次收到串口数据的时间戳
#define COM_TIMEOUT 500    // 超时时间 500ms (验收标准要求具备自动急停)

// PID 结构体
typedef struct {
  float Kp, Ki, Kd;
  float prev_error;
  float integral;
  float i_limit;
} PID_t;

// PID 参数 (针对 JGA25-370 调整)
// Kp: 响应力度, Ki: 消除静态误差(跑直线的关键), Kd: 抑制震荡
PID_t pid_L = {600.0f, 78.0f, 0.0f, 0.0f, 0.0f, 1500.0f};
PID_t pid_R = {600.0f, 80.0f, 0.0f, 0.0f, 0.0f, 1500.0f};

uint32_t last_time = 0;

// 串口变量
// 接收缓冲区，用于 HAL_UART_Receive_IT
uint8_t rx_buffer[1];
// 数据帧缓冲区，用于存储接收到的完整数据帧
uint8_t data_buffer[10];
// 数据帧当前接收到的字节数
uint8_t data_index = 0;
// 串口接收状态机
#define STATE_WAIT_HEADER 0
#define STATE_RECEIVE_BODY 1
uint8_t rx_state = STATE_WAIT_HEADER;

// 电机方向定义 (根据实际接线调整 1 或 -1)
#define MOTOR_L_POLARITY 1
#define MOTOR_R_POLARITY 1

// 运动模式定义
#define MODE_SPEED 0x01 // 速度控制模式
#define MODE_TURN_ANGLE 0x02 // 转向角度控制模式
#define MODE_TURN_LEFT 0x03 // 左转模式
#define MODE_TURN_RIGHT 0x04 // 右转模式
#define MODE_ROTATE_LEFT 0x05 // 左自转模式
#define MODE_ROTATE_RIGHT 0x06 // 右自转模式

// 转向控制变量
volatile float target_angle = 0.0f; // 目标转向角度 (度)
/* USER CODE END 0 */

/**
 * @brief  The application entry point.
 * @retval int
 */
int main(void) {

  /* MCU Configuration--------------------------------------------------------*/

  /* Reset of all peripherals, Initializes the Flash interface and the Systick.
   */
  HAL_Init();

  /* Configure the system clock */
  SystemClock_Config();

  /* Initialize all configured peripherals */
  MX_GPIO_Init();
  MX_TIM2_Init();
  MX_USART1_UART_Init();
  MX_TIM3_Init();
  MX_TIM4_Init();
  /* USER CODE BEGIN 2 */

  // --- 强制初始化 PA0 和 PA1 为复用推挽输出 (PWM模式) ---
  // 1. 开启 GPIOA 时钟
  __HAL_RCC_GPIOA_CLK_ENABLE();

  GPIO_InitTypeDef GPIO_InitStruct = {0};

  // 2. 配置 PA0 (TIM2_CH1) 和 PA1 (TIM2_CH2)
  GPIO_InitStruct.Pin = GPIO_PIN_0 | GPIO_PIN_1;
  GPIO_InitStruct.Mode = GPIO_MODE_AF_PP; // 关键：复用推挽输出
  GPIO_InitStruct.Speed = GPIO_SPEED_FREQ_HIGH;
  HAL_GPIO_Init(GPIOA, &GPIO_InitStruct);

  // 1. 开启 PWM 输出
  HAL_TIM_PWM_Start(&htim2, TIM_CHANNEL_1);
  HAL_TIM_PWM_Start(&htim2, TIM_CHANNEL_2);

  // 2. 开启编码器计数模式
  HAL_TIM_Encoder_Start(&htim3, TIM_CHANNEL_ALL);
  HAL_TIM_Encoder_Start(&htim4, TIM_CHANNEL_ALL);

  // 开启串口中断
  HAL_UART_Receive_IT(&huart1, rx_buffer, 1);

  // 初始化看门狗时间
  last_rx_time = HAL_GetTick();

  // 初始化编码器计数器为0，防止启动时有随机值
  __HAL_TIM_SET_COUNTER(&htim3, 0);
  __HAL_TIM_SET_COUNTER(&htim4, 0);

  // 5. 初始化时间戳
  last_time = HAL_GetTick();

  /* USER CODE END 2 */

  /* Infinite loop */
  /* USER CODE BEGIN WHILE */
  // HAL_GPIO_WritePin(GPIOA, GPIO_PIN_0, GPIO_PIN_SET);
  // GPIOA->CRL &= 0xFFFFFFF0; GPIOA->CRL |= 0x00000003; GPIOA->ODR |= 1;
  while (1) {
    // 50ms 控制周期
    if (HAL_GetTick() - last_time >= CONTROL_PERIOD) {
      last_time = HAL_GetTick();
      Control_Loop();
    }

    /* USER CODE END WHILE */

    /* USER CODE BEGIN 3 */
  }
  /* USER CODE END 3 */
}

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
/* USER CODE BEGIN 4 */

// --- 串口接收回调 ---
// 串口接收中断回调函数
void HAL_UART_RxCpltCallback(UART_HandleTypeDef *huart) {
  if (huart->Instance == USART1) {
    // 喂狗：只要有中断进来，就更新时间戳
    // 注意：更严格的做法是校验成功后再更新，但防断连这样够用了
    last_rx_time = HAL_GetTick();

    uint8_t received_byte = rx_buffer[0];

    switch (rx_state) {
    case STATE_WAIT_HEADER:
      if (received_byte == 0xA5) { // 帧头检测
        data_index = 0;
        data_buffer[data_index++] = received_byte;
        rx_state = STATE_RECEIVE_BODY;
      }
      break;

    case STATE_RECEIVE_BODY:
      if (data_index < sizeof(data_buffer)) {
        data_buffer[data_index++] = received_byte;
        // 假设数据帧格式为：A5 [功能码] [数据1] [数据2] ... [数据N] [校验和]
        // 速度控制帧：A5 01 [速度值] 00 00 00 00 00 [校验和] (共9字节，速度值1字节)
        // 转向角度控制帧：A5 02 [角度高字节] [角度低字节] 00 00 00 00 [校验和] (共9字节，角度值2字节)
        // 左转/右转/左自转/右自转帧：A5 0X [速度值] 00 00 00 00 00 [校验和] (共9字节，速度值1字节)
        // 这里简化处理，只检查到第9个字节
        if (data_index >= 9) { // 接收完整一帧 (帧头 + 功能码 + 6字节数据 + 校验和)
          uint8_t function_code = data_buffer[1];
          uint8_t checksum = 0;
          for (int i = 0; i < 8; i++) { // 计算校验和 (从帧头到数据N)
            checksum += data_buffer[i];
          }

          if (checksum == data_buffer[8]) { // 校验和正确
            if (function_code == MODE_SPEED) { // 速度控制模式
              // 数据格式: A5 01 [速度值] 00 00 00 00 00 [校验和]
              // 速度值范围 -100 到 100，对应 -1.0m/s 到 1.0m/s
              int8_t speed_cmd = (int8_t)data_buffer[2];
              float target = speed_cmd / 100.0f; // 解析速度，转换为 m/s

              // 更新最终目标速度
              final_speed_L = target;
              final_speed_R = target;

            } else if (function_code == MODE_TURN_ANGLE) { // 转向角度控制模式
              // 数据格式: A5 02 [角度高字节] [角度低字节] 00 00 00 00 [校验和]
              // 角度值范围 -36000 到 36000，对应 -360.00度 到 360.00度
              // 实际发送时，将角度值乘以100，然后拆分成高低字节发送
              // 例如：发送 90.50 度，则发送 9050，高字节为 (9050 >> 8) & 0xFF，低字节为 9050 & 0xFF
              int16_t angle_cmd = (int16_t)((data_buffer[2] << 8) | data_buffer[3]);
              target_angle = (float)angle_cmd / 100.0f; // 解析角度，转换为度

              // 在这里，你可以根据 target_angle 设置左右轮的差速，实现转向
              // 例如：
              // 如果 target_angle > 0，左转，左轮速度减小，右轮速度增大
              // 如果 target_angle < 0，右转，左轮速度增大，右轮速度减小
              // 具体的转向逻辑需要在 Control_Loop 中实现，这里只是接收指令
              // 为了简化，这里暂时只更新 target_angle，Control_Loop 会根据此值进行调整
              // 注意：这里只是一个示例，实际的转向控制可能需要更复杂的算法
            } else if (function_code == MODE_TURN_LEFT) { // 左转模式
              int8_t speed_cmd = (int8_t)data_buffer[2];
              float target_speed = speed_cmd / 100.0f;
              final_speed_L = target_speed * 0.5f; // 左轮减速
              final_speed_R = target_speed * 1.0f; // 右轮保持
            } else if (function_code == MODE_TURN_RIGHT) { // 右转模式
              int8_t speed_cmd = (int8_t)data_buffer[2];
              float target_speed = speed_cmd / 100.0f;
              final_speed_L = target_speed * 1.0f; // 左轮保持
              final_speed_R = target_speed * 0.5f; // 右轮减速
            } else if (function_code == MODE_ROTATE_LEFT) { // 左自转模式
              int8_t speed_cmd = (int8_t)data_buffer[2];
              float target_speed = speed_cmd / 100.0f;
              final_speed_L = -target_speed; // 左轮反转
              final_speed_R = target_speed;  // 右轮正转
            } else if (function_code == MODE_ROTATE_RIGHT) { // 右自转模式
              int8_t speed_cmd = (int8_t)data_buffer[2];
              float target_speed = speed_cmd / 100.0f;
              final_speed_L = target_speed;  // 左轮正转
              final_speed_R = -target_speed; // 右轮反转
            }
          }

          data_index = 0;
          rx_state = STATE_WAIT_HEADER;
        }

      } else { // 数据溢出，重新等待帧头
        data_index = 0;
        data_buffer[data_index++] = received_byte;
        rx_state = STATE_RECEIVE_BODY;
      }
      break;
    }
    HAL_UART_Receive_IT(&huart1, rx_buffer, 1);
  }
}

// --- PID 计算核心 ---
// --- PID 计算函数 ---
// 输入：目标速度，当前速度，PID参数包
// 输出：PWM值 (-1000 ~ 1000)
int16_t PID_Compute(float target, float current, PID_t *pid) {
  float error = target - current;

  // 积分项 (消除静差)
  pid->integral += error;

  // 积分限幅 (使用 struct 中的 i_limit)
  if (pid->integral > pid->i_limit)
    pid->integral = pid->i_limit;
  if (pid->integral < -pid->i_limit)
    pid->integral = -pid->i_limit;

  // 微分项 (阻尼作用)
  float derivative = error - pid->prev_error;

  // PID 公式
  float output =
      (pid->Kp * error) + (pid->Ki * pid->integral) + (pid->Kd * derivative);

  pid->prev_error = error;

  // PWM 限幅 (应与 PWM_MAX_VALUE 匹配)
  if (output > PWM_MAX_VALUE)
    output = PWM_MAX_VALUE;
  if (output < -PWM_MAX_VALUE)
    output = -PWM_MAX_VALUE;

  return (int16_t)output;
}

// --- 速度斜坡函数 (实现平稳起步的关键) ---
// 将 current 向 target 靠近，但每次变化量不超过 step
float Apply_Ramp(float current, float target, float step) {
  if (current < target) {
    current += step;
    if (current > target)
      current = target; // 防止超调
  } else if (current > target) {
    current -= step;
    if (current < target)
      current = target;
  }
  return current;
}

void Control_Loop(void) {
  // 1. 安全检查：通信超时自动急停 (如果你想测试长跑，把 COM_TIMEOUT 改大，比如 5000)
  if (HAL_GetTick() - last_rx_time > COM_TIMEOUT) {
    final_speed_L = 0.0f;
    final_speed_R = 0.0f;
  }

  // 2. 速度平滑处理 (斜坡算法)
  ramped_speed_L = Apply_Ramp(ramped_speed_L, final_speed_L, ACCEL_STEP);
  ramped_speed_R = Apply_Ramp(ramped_speed_R, final_speed_R, ACCEL_STEP);

  // 3. 读取编码器并计算真实速度
  int16_t cur_cnt_L = (int16_t)__HAL_TIM_GET_COUNTER(&htim3);
  int16_t cur_cnt_R = (int16_t)__HAL_TIM_GET_COUNTER(&htim4);

  int16_t diff_L = (cur_cnt_L - last_count_L) * MOTOR_L_POLARITY;
  int16_t diff_R = (cur_cnt_R - last_count_R) * MOTOR_R_POLARITY;

  last_count_L = cur_cnt_L;
  last_count_R = cur_cnt_R;

  current_speed_L = (float)diff_L * SPEED_RATIO;
  current_speed_R = (float)diff_R * SPEED_RATIO;

  // 4. PID 计算 (新增：静止死锁逻辑，解决抽搐问题)
  int16_t pwm_out_L = 0;
  int16_t pwm_out_R = 0;

  // --- 左轮处理 ---
  // 如果目标速度极小（认为是要停车），强制关断
  if (fabs(ramped_speed_L) < 0.001f) {
      pwm_out_L = 0;
      pid_L.integral = 0.0f;     // 清除积分，防止再次启动时猛冲
      pid_L.prev_error = 0.0f;   // 清除微分历史
  } else {
      // 只有在需要动的时候，才启动 PID
      pwm_out_L = PID_Compute(ramped_speed_L, current_speed_L, &pid_L);
  }

  // --- 右轮处理 ---
  if (fabs(ramped_speed_R) < 0.001f) {
      pwm_out_R = 0;
      pid_R.integral = 0.0f;
      pid_R.prev_error = 0.0f;
  } else {
      pwm_out_R = PID_Compute(ramped_speed_R, current_speed_R, &pid_R);
  }

  // 5. 执行输出
  Set_Motor_Speed(pwm_out_L, pwm_out_R);
}
/* USER CODE END 4 */
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


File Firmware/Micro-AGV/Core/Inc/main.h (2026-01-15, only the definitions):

#define Motor_R_PWM_Pin GPIO_PIN_0
#define Motor_R_PWM_GPIO_Port GPIOA
#define Motor_L_PWM_Pin GPIO_PIN_1
#define Motor_L_PWM_GPIO_Port GPIOA
#define L_IN1_Pin GPIO_PIN_12
#define L_IN1_GPIO_Port GPIOB
#define L_IN2_Pin GPIO_PIN_13
#define L_IN2_GPIO_Port GPIOB
#define R_IN1_Pin GPIO_PIN_14
#define R_IN1_GPIO_Port GPIOB
#define R_IN2_Pin GPIO_PIN_15
#define R_IN2_GPIO_Port GPIOB

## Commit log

2025-12-03 添加可行性报告
    初版框架
2025-12-03 STM32F103ZE数据手册
2025-12-03 结构设计
2025-12-05 Create 硬件手册
2025-12-05 Refactor project structure (重构项目目录结构)
2025-12-06 硬件详情
2025-12-06 update datasheets
    [STM32F103C8T6.SCHLIB, STM32F103C8T6核心板.PcbDoc, STM32F103C8T6核心板.PcbLib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]
2025-12-11 软件框架
    Init: HAL drivers and project skeleton (CubeMX)
2025-12-15 Impl: Basic motor control logic (Open Loop)
2026-01-19 转弯功能

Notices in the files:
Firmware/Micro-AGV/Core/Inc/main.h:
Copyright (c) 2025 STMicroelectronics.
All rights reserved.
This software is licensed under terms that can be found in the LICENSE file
